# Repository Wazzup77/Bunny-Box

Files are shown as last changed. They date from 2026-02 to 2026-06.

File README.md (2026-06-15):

<p align="center">
  A bunny in the style of the Qidi Box
  <h1 align="center">Bunny Box</h1>
</p>

<p align="center">
Qidi Box open source makeover using Happy Hare
</p>

Bunny Box is the Qidi Box mod that allows you to ditch Qidi's closed-source, proprietary firmware and use [Happy Hare](https://github.com/moggieuk/Happy-Hare/) to control your Box. With added support for Qidi-specific qirks such as the extruder hall sensor and above-extruder cutter placement, this allows Qidi Box use with Freedi and Kalico as well as using non-Qidi multimaterial units with Qidi printers. Strong defaults are provided, but the beauty of Happy Hare is that almost anything can be tweaked!

## FEATURES

 * Open source alternative to Qidi's Box control
    * No more .so files (you can update Python again)
    * Full control over Qidi Box configuration
    * Make the Qidi Box work on older Qidi and non-Qidi printers

 * Fully featured Happy Hare
    * Tip forming - save filament by reducing waste
    * the entire loading process can be tinkered with - increase loading speeds, change toolchange sequences, etc.
    * Spoolman support for better filament management
    * configurable LED effects depending on print / filament state

 **NOT SUPPORTED:**
 * RFID tags - maybe in the future, but honestly who cares?

## DEVELOPMENT STATUS

 * [**Qidi Happy Hare fork**](https://github.com/Wazzup77/Happy-Hare) - works, but not yet pulled into mainline. The `bunnybox` branch is used as the installation source. Q2 and Max4 users can install mainline Happy Hare.
 * [**Plus4**](Plus4) - works, tested on Qidi's 1.7.3, FreeDi (so stock Klipper) and Kalico (with minor issues still to be resolved).
 * [**Q2**](Q2) - testing in progress!
 * [**Max4**](Max4) - **HACKERS WANTED** - The Max4 firmware stack is materially more complex than Plus4/Q2 - it's split into multiple smaller .cfg files and has additional closed-source modules. Brave volunteers that own the Max4 are encouraged to reach out and help figure it out!

 Should be compatible with Beacon/Cartographer mods.

## ISSUES / TODO
* Printer screen is broken on stock Qidi firmware while in print - probably won't be fixed
* Qidi Studio sync is not working
* Power-loss recovery is disabled. Qidi's PLR depends on closed-source code (binary `.so` on Plus4, shell scripts on Q2) and cannot restore MMU tool/gate state. The stock `DETECT_INTERRUPTION` popup ("Resume last print?") would auto-cancel on timeout and, even if accepted, would resume with the wrong filament. Our `bunnybox_macros.cfg` overrides `DETECT_INTERRUPTION` to silently clear the flag so the popup never appears.

If you run into issues please report them in the issue tracker here. We are also on Qidi's Discord server [in a dedicated thread](https://discord.com/channels/1184400034641477722/1443579858679500822) if you want to chat.

## HAPPY HARE FORK

We are for now relying on a fork of Happy Hare until our new features are pulled to mainline. This is necessary for handling of the hall effect sensor in the extruder of Qidi printers and Qidi's weird cutter configuration. 

[Happy Hare Qidi Fork](https://github.com/Wazzup77/Happy-Hare/).

## HARDWARE REFERENCE

* [Qidi Box Pinout](qidi_box_pinout.md)
* [Qidi Box DFU Flashing Guide](dfu_flash.md)

## ADDITIONAL HELP

Refer to the [Happy Hare documentation](https://github.com/moggieuk/Happy-Hare/wiki).

## Frequenty Asked Questions

<details>
<summary> Do I need to flash the Qidi Box firmware? </summary>

No! Qidi Box already runs Klipper (Qidi's fork). Since the Box is a slave to the host (printer), flashing is not needed regardless of if you are connecting to a Qidi printer, a Qidi printer flashed with FreeDi or Kalico, or a non-Qidi printer. Nonetheless, you can flash it - the instructions are [here](dfu_flash.md).

</details>

<details>
<summary> How do I go back to the stock firmware?  </summary>

Re-run the installer script for your printer ([Plus4](Plus4/install-bb-p4.sh), [Q2](Q2/install-bb-q2.sh), [Max4](Max4/install-bb-max4.sh)). If it detects an existing bunnybox install it will offer **2) Revert to stock**, which restores `printer.cfg` and the stock macro file from the oldest `backup_hh_*` directory and clears `mmu__revision`. The current bunnybox state is preserved in a new `backup_revert_<timestamp>/` so the revert itself can be undone.

To script the revert (no menu prompt), pass `--revert` to the installer — see the "Reverting to stock" section in each printer's README ([Plus4](Plus4/README.md#reverting-to-stock), [Q2](Q2/README.md#reverting-to-stock), [Max4](Max4/README.md#reverting-to-stock)).

If no `backup_hh_*` directory exists (e.g. the install was done manually), restore your own backups of `printer.cfg` and `gcode_macro.cfg` (or `klipper-macros-qd/` on Max4), delete the `mmu/` folder and `bunnybox_macros.cfg` from your config directory, remove the `mmu__revision` line from `saved_variables.cfg`, and restart Klipper.

</details>

<details>
<summary> How do I update without losing my tuning and calibration? </summary>

Just re-run the installer for your printer. When it detects an existing install and you choose **1) Reinstall / update**, your config is no longer overwritten wholesale. The update is split between two installers that own different parts of the config:

**Happy Hare's own installer** handles everything it manages: the MMU *logic* files (`mmu_cut_tip.cfg`, `mmu_sequence.cfg`, `mmu_software.cfg`, …, which it installs as symlinks into `~/Happy-Hare`), and your *parameters* (`mmu_parameters.cfg`, `mmu_macro_vars.cfg`, addon configs), whose values it carries forward as it upgrades them. **Your calibration (`mmu/mmu_vars.cfg`) is left untouched.** This is why the bundled copies of those files in this repo can look "behind" — they're only reference snapshots; the live versions come from the Happy Hare fork at install time.

**Bunny Box's smart merge** handles only the files Happy Hare leaves frozen and that Bunny Box truly owns: `mmu_hardware.cfg` (Qidi pins), `mmu.cfg`, the addon `*_hw.cfg` hardware files, and the top-level `bunnybox_macros.cfg`. For these it does a **3-way merge** against a snapshot of what it last installed (`printer_data/config/.bunnybox_base`, recorded by a `.bunnybox_manifest`):

* Files you never edited but that changed upstream are **updated to the new defaults** automatically.
* Files you edited but that didn't change upstream are **left exactly as you have them**.
* Files where your edits *and* the new defaults overlap are **merged**; if they collide on the same lines the installer **asks you per file** whether to keep yours, take the new version, or write a `*.bbmerge` copy with conflict markers to resolve by hand.

When run from a git clone it also prints a short **changelog** of the config commits between your installed version and the latest. A full backup is still saved to `backup_hh_<timestamp>/` every time, so any update is reversible.

> Note: the Bunny Box smart merge now ships on all three installers (**Plus4**, **Q2** and **Max4**). Plus4 installs Happy Hare from the [`bunnybox` fork](https://github.com/Wazzup77/Happy-Hare); Q2 and Max4 install mainline Happy Hare. In all cases Happy Hare's installer owns the logic/parameter upgrade and Bunny Box's smart merge owns the hardware/macro layer.

</details>

<details>
<summary> Can you add support for my printer? </summary>

I only have a Plus4 and so can't really make other printers work. There are people with the Q2 who are using Bunny Box though, so that will likely come soon. For the Max4, I don't have one, so that will only come if someone else makes it. As for older ones/non-Qidi printers, you're on your own - I don't have one and think it's unlikely anyone will make one for you.

</details>

<details>
<summary> I'm a bit of a noob, can you help me? </summary>

Unfortunately I probably won't be able to help you much - I'm pretty busy and issues with Happy Hare are very difficult to diagnose without having phyiscal access to the machine and full knowledge of its configuration. If you decide to use this, be aware that you are expected to read [Happy Hare documentation](https://github.com/moggieuk/Happy-Hare/wiki) and understand what you are doing.

</details>

<details>
<summary> I changed the speeds in mmu_parameters.cfg, why are loads weird now? </summary>

Qidi's encoder is not that great unfortunately. It's measurement will vary widely depending on speed. At the same time you cannot really adjust its sensitivity parameter, since it is used for clog detetion during print (when the filament is moving slowly). In effect, you should calibrate the lengts of tubes after changing speeds (using the encoder calibration routire in HH). 

</details>

<details>
<summary> My filament is grinding in the gears </summary>

Repeated load/unload cycles without any significant extrusion will cause the filament to grind in the gears. This is normal.

</details>

<details>
<summary> I'm getting false-positive runouts on filament changes! </summary>

You probably forgot to remove the runout from your [hall_filament_width_sensor] section in printer.cfg! Comment out the runout gcode and the pause on runout parameter, or remove the entire section.

</details>

<details>
<summary> I think my config is awesome, can I share it here? </summary>
Yes! Please create a PR. If you are able to make a distint configuration (e.g. for a different printer or compatible with stock Qidi gcode) please make a new folder for it and add a README describing the configuration and installation. Small configuration tweaks can be made to the base configs, but should be well described and justified.

</details>

<details>
<summary> I love this mod! Happy Hare is great! How can I make it even better!? </summary>
Fit a [proportional filament sensor (PFS)](addons/PFS) in place of the stock filament tangle sensor — it gives Happy Hare analog sync-feedback for tighter gear/extruder syncing and smarter clog/tangle detection. See [addons/PFS](addons/PFS/README.md) for the build, wiring and calibration guide.

</details>

## CONTRIBUTING

PRs are welcome! Just make sure to describe what system you're working with (Qidi Klipper, Klipper or Kalico) and what other mods you have.
We prefer strong defaults that should work with everyone here, even if they are not optimal. Go slower or more wasteful by default, let willing users tune it to their demands.

## SUPPORT THE PROJECT

[Support Happy Hare instead!](https://www.paypal.me/moggieuk)

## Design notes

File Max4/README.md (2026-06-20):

> [!CAUTION]
> **Max4 support is experimental — hackers wanted, do not install on a working printer.** The Max4 firmware stack is materially more complex than Plus4 or Q2 and the HH integration is only partially mapped out. If something fails, you are expected to diagnose and fix it.
>
> **What's different about the Max4:**
> - It adds a second closed-source state machine, `multi_color_controller.so`, on top of the `box_extras` / `box_autofeed` / `box_stepper` / `box_rfid` stack shared with Plus4/Q2. `multi_color_controller` implements both local orchestration and a USB-JSON protocol to the second-gen box.
> - The macro layer is built on [Justin Schuh's klipper-macros](https://github.com/jschuh/klipper-macros) (packaged as `klipper-macros-qd`) with a phased `PRINT_START` (`_PRINT_START_PHASE_INIT` → `_PRINT_START_BOX_PREPAR` → `_PRINT_START_PHASE_PREHEAT` → `_PRINT_START_PHASE_PROBING` → `_PRINT_START_PHASE_EXTRUDER`) rather than the single flat `gcode_macro.cfg` pattern of Plus4/Q2. Lowercase section names (`[gcode_macro pause]`, `[gcode_macro clear_pause]`) are used. This is more complex to modify and will require live testing which I cannot do (I do not own a Max4).
> - Closed-source dependencies extend beyond the box: `probe_air`, `multi_color_controller`, `d_bus_service_manager`, `ai_func_manager`, `print_stats_manager`, `smart_output_pin`, `cl_interface`, `closed_loop`. This should be avoidable, since Happy Hare allows us to remove Qidi box-related configs and thus prevent the .so files from loading. However, for the Max4, the .so files extend further beyond the Plus4/Q2 scope, so hidden dependancies may emerge.

# INSTALLATION

> [!IMPORTANT]
> **Unload all filament from the box before you start.** Once Happy Hare is installed you cannot load or unload filament until [calibration](#-calibration--required-before-first-use) is done, and gear calibration has to be performed with the filament cut flush at the gate — not fully loaded. Unload every gate now, while the stock Qidi firmware is still in control.

## AUTO INSTALLATION

The easiest way to install Happy Hare on your Qidi Max4 is to use the provided automated script. 

1. **Connect to your printer** via SSH.
2. **Download and run the script**:
   ```bash
   wget -qO - https://raw.githubusercontent.com/Wazzup77/Bunny-Box/refs/heads/main/Max4/install-bb-max4.sh | bash
   ```
   
The script will backup your configurations, download the necessary files, prompt you for your serial ID, and automatically install Happy Hare.
Don't forget to update the machine gcodes in the slicer to use the ones provided in the [slicer_machine_gcodes.md](./config_hh-standalone/slicer_machine_gcodes.md).

> [!CAUTION]
> **The installer does NOT calibrate your MMU.** After installation you MUST calibrate before your first print — see [CALIBRATION — REQUIRED BEFORE FIRST USE](#-calibration--required-before-first-use) at the bottom of this guide. This is the most commonly missed step.

## REVERTING TO STOCK

The installer script doubles as the uninstaller. Re-run it on a printer where bunnybox / Happy Hare is already installed and it will offer a revert option:

```bash
wget -qO - https://raw.githubusercontent.com/Wazzup77/Bunny-Box/refs/heads/main/Max4/install-bb-max4.sh | bash
```

When the menu appears, choose **2) Revert to stock**. The script will:
- restore `printer.cfg` and the `klipper-macros-qd/` directory from the oldest `backup_hh_*` directory (your pre-install snapshot),
- move the current `bunnybox_macros.cfg` and `mmu/` folder into a new `backup_revert_<timestamp>/` so the revert itself can be undone,
- clear `mmu__revision` from `saved_variables.cfg`, and
- restart Klipper and Moonraker with `sudo systemctl restart klipper` or a power cycle.

### Non-interactive revert (for scripts)

If you want to call the revert from another script, pass `--revert` to skip the menu entirely:

```bash
# Standalone (one-liner)
wget -qO - https://raw.githubusercontent.com/Wazzup77/Bunny-Box/refs/heads/main/Max4/install-bb-max4.sh | bash -s -- --revert

# Or from a cloned repo
./install-bb-max4.sh --revert
```

Use `--help` to see all flags. The revert leaves the cloned `~/Happy-Hare/` repo and the custom `aht10.py` module on disk; they are harmless once `printer.cfg` no longer references them.

## MANUAL INSTALLATION

### STEP 1: HAPPY HARE INSTALLATION
<details>
<summary> HAPPY HARE INSTALL </summary>

1. Select your config variant. At present, you can select from:

- [`config_hh-standalone`](./config_hh-standalone/README.md) - Happy Hare focused config, taking advantage of its features for a more Happy-Hare experience

2. Copy the configs (`mmu` folder and `bunnybox_macros.cfg`) from the selected variant to your printer's config folder.

3. Add your printer's serial address to `mmu/base/mmu.cfg`. To do this, connect to your printer via SSH and run:

```bash
ls /dev/serial/by-id/*
```

This will give you a list of USB devices. It should say something like:

```bash
/dev/serial/by-id/usb-Klipper_QIDI_BOX_xxxxxxxxxxxxxxxxxxxxxxxxxx
```

Copy that into your mmu.cfg in the `serial:` parameter, replacing the old value.

4. Install Happy Hare from the [Qidi Box fork](https://github.com/Wazzup77/Happy-Hare). To do this, connect to your printer via SSH and run:

```bash
cd ~
git clone -b bunnybox https://github.com/Wazzup77/Happy-Hare.git
```

5. Run the install script `Happy-Hare/install.sh` and pray that it does not break stuff.

```bash
./Happy-Hare/install.sh
```

6. Add `mmu__revision = 0` to `saved_variables.cfg'

```bash
echo "mmu__revision = 0" >> printer_data/config/saved_variables.cfg
```

7. Restart Klipper

```bash
sudo service klipper restart
```
</details>

### STEP 2: printer.cfg CHANGES

<details>
<summary> `[printer.cfg]` CHANGES </summary>

0. Backup your printer.cfg file! Just in case you want to return to the stock config.

1. Remove Qidi's stock box config `[include box.cfg]` and `[multi_color_controller]`.

2. Modify the `[filament_switch_sensor filament_switch_sensor]` section (HH takes care of runout). **Important:** Set `pause_on_runout` to `False` — do not comment it out, as Klipper defaults to `True`:
```diff
+[duplicate_pin_override]
+pins: THR:PA0
+
[filament_switch_sensor filament_switch_sensor]
-pause_on_runout: True
+pause_on_runout: False
-runout_gcode:
-            M118 Filament run out
-            {% set can_auto_reload = printer.save_variables.variables.auto_reload_detect|default(0) %}
-            {% if can_auto_reload == 1 %}
-              AUTO_RELOAD_FILAMENT
-            {% endif %}
-insert_gcode:             # Code executed when inserting consumables
event_delay: 3.0          # event delay time
pause_delay: 0.5          # pause delay time
switch_pin:!THR:PA0       # Detect switch pin
```

> **The installer does the `[duplicate_pin_override]` + pin sync for you** — it reads the stock sensor's `switch_pin` and writes it into both the override and `mmu_hardware.cfg`'s `extruder_switch_pin`. You only need this step if installing by hand.
>
> **FreeDi / Kalico users:** those firmwares may name the toolhead MCU something other than `THR` (e.g. `Toolhead`). If so, the stock `switch_pin` will read `Toolhead:PA0` (not `THR:PA0`), and `extruder_switch_pin` in `mmu_hardware.cfg` plus the `[duplicate_pin_override]` pin must use that **same** name. Copy it from your own printer.cfg — a hardcoded `THR` that doesn't exist fails to load with `MCU 'THR' not found`.

3. Add `[include bunnybox_macros.cfg]` at the top.

4. Make sure Happy Hare files were included during install in printer.cfg: 
```
[include mmu/base/*.cfg]
[include mmu/optional/client_macros.cfg]
```
Other mmu directories should not be included!

5. **Recommended:** Wrap the `[idle_timeout]` gcode so it does not kill the box heaters during a Happy Hare drying cycle (`MMU_HEATER DRY=1`). Without this, an `idle_timeout` shorter than your drying cycle will turn off the heaters mid-dry. Stock Qidi ships with `timeout: 43200` (12 hours), so this only matters if you've shortened the timeout or want to dry for longer than 12 hours.

```diff
[idle_timeout]
timeout: 43200
gcode:
-    PRINT_END
+    {% if printer.mmu is defined and printer.mmu.drying_state[0] == 'active' %}
+      SET_HEATER_TEMPERATURE HEATER=extruder TARGET=0
+      SET_HEATER_TEMPERATURE HEATER=heater_bed TARGET=0
+      SET_HEATER_TEMPERATURE HEATER=chamber TARGET=0
+    {% else %}
+      PRINT_END
+    {% endif %}
```

   If your `[idle_timeout]` section only has `timeout:` and no `gcode:` block, you are relying on Klipper's implicit default of `TURN_OFF_HEATERS` + `M84`. Add the wrapped block to the section, with `TURN_OFF_HEATERS` and `M84` as the `{% else %}` branch.

</details>

### STEP 3: klipper-macros-qd CHANGES

<details>
<summary> `klipper-macros-qd` CHANGES </summary>

0. Backup your `klipper-macros-qd` folder! Just in case you want to return to the stock config.

1. In `start_end.cfg`:
```diff
[gcode_macro print_start]
description: Usage: PRINT_START BED=<temp> HOTEND=<temp> [CHAMBER=<temp>] EXTRUDER = <num>
                     [MESH_MIN=<x,y>] [MESH_MAX=<x,y>] [LAYERS=<num>]
                     [NOZZLE_SIZE=<mm>]
gcode:
  # Set the printing master status to the starting stage
  SET_PRINT_MAIN_STATUS MAIN_STATUS=print_start
  # ===Print the four core stages of startup ===
  _PRINT_START_PHASE_INIT {rawparams}   # Phase 1: Initialize setup and start bed/chamber preheating
-  _PRINT_START_BOX_PREPAR               # Stage 2: Multi-color consumable preparation and switching

  _PRINT_START_PHASE_PREHEAT            # Phase 3: Temperature stabilization and shaft return
  _PRINT_START_PHASE_PROBING            # Stage 4: Detection calibration (bed net/gantry leveling)
  _PRINT_START_PHASE_EXTRUDER           # Stage 5: Final warm-up of the extruder
  # Switch to official printing status
  SET_PRINT_MAIN_STATUS MAIN_STATUS=printing
```
2. In `pause_resume_cancel.cfg`:
    - Remove `pause` / `PAUSE` (or comment it out — note Max4 stock uses lowercase).
    - Remove `RESUME_PRINT` (or comment it out).
    - Remove `RESUME` (or comment it out).
    - Remove `CANCEL_PRINT` (or comment it out).
    - Remove `clear_pause` (or comment it out — references variables on `RESUME_PRINT` so it would throw after step 2 above).

3. If any config file in your install defines `[gcode_macro DETECT_INTERRUPTION]`, comment it out. `bunnybox_macros.cfg` provides a no-op replacement; commenting rather than using `rename_existing:` keeps the install working on mainline Klipper / FreeDi where the stock macro may already be absent. (Stock Max4 does not define this macro in any visible config — this step is a no-op for stock Max4 installs.)

4. In `start_end.cfg`, comment out any `save_last_file` call inside `PRINT_START`. This is Qidi's power-loss recovery hook and sets `was_interrupted=True` in `saved_variables.cfg` on every print start; PLR is disabled under Happy Hare (see [DETECT_INTERRUPTION override](./config_hh-standalone/bunnybox_macros.cfg)) so the call is wasteful.

</details>

### STEP 4: USER INTERFACE

<details>
<summary> USER INTERFACE </summary>

If you want to have a section in your printer web interface, install baseline fluidd or mainsail, which both have HH implemented. You can do that via kiauh, which comes preinstalled on Qidi printers.

1. Update kiauh

```bash
    cd kiauh
    git pull
```

2. Run kiauh to reinstall fluidd or mainsail

```bash
    ./kiauh.sh
```

You want to REMOVE the existing Fluidd installation and install it again - this will move you from the Qidi version to mainline, which supports Happy Hare.
Alternatively you can also install Mainsail instead of Fluidd.

</details>

### STEP 5: SLICER SETTINGS

<details>
<summary> SLICER SETTINGS </summary>

Use the [following machine g-codes](./config_hh-standalone/slicer_machine_gcodes_hh.md) with your slicer.

</details>

### (optional) STEP 6: ENVIRONMENT SENSOR

<details>
<summary> ENVIRONMENT SENSOR </summary>

> If you are on mainline Klipper, Freedi or Kalico, you can skip this step altogether, though it won't hurt anything if you do it. I recommend doing this step for stability, but you can skip it by changing the `[temperature_sensor box1_env]` `sensor_type` to `AHT10` in the `mmu_hardware.cfg`. 

To be able to view temperature and humidity in the printer web interface reliably, you need to install a aht10.py module from modern Klipper. 

1. Go to the Klipper directory and clone the module

```bash
    cd klipper/klippy/extras

    sudo mv aht10.py aht10.py.bak

    wget https://raw.githubusercontent.com/Wazzup77/Bunny-Box/refs/heads/main/aht10.py
```

</details>

# ⚠️ CALIBRATION — REQUIRED BEFORE FIRST USE

> [!CAUTION]
> **Happy Hare will NOT load filament or print reliably until it is calibrated.** Whether you used the auto installer or installed manually, calibration is a separate, mandatory step done once after installation, before your first print. It is the single most commonly missed step.

On the Max4 (no encoder):

- **Gear calibration** (`MMU_CALIBRATE_GEAR`) — ✅ **REQUIRED**
- Bowden length (`MMU_CALIBRATE_BOWDEN`) — *optional*

Follow the official [Happy Hare — Type B Calibration wiki](https://github.com/moggieuk/Happy-Hare/wiki/MMU-Calibration-TypeB) for the exact procedure and commands.

# ADDITIONAL TUNING

1. Speed! The default Qidi profile is very slow. You can speed it up by increasing the values in the SPEEDS section in mmu_parameters.cfg. Keep in mind that these settings will vary between different Qidi Boxes. Generally loading speeds can be increased by 20-30% without issues, but keep in mind that going fast may cause filament swaps to fail. Going too fast may also cause the filament to be ground up by the gears. Remember to recalibrate the encoder after changing speeds (its measurement will vary widely depending on speed).
2. Tip forming. The base configuration uses the cutter. Tip forming allows you to reduce filament waste by removing the whole filament piece from the hotend. The disadvantage is that good tuning is needed to avoid clogs. Although the profile in these configs has been tested on multiple filaments across multiple Plus4 printers, it may require tuning on your specific printer/filament. If you have a custom hotend, you need to update the configration too. Activate it by changing: 
`form_tip_macro: _MMU_CUT_TIP` to `form_tip_macro: _MMU_FORM_TIP`
To additionally improve the movement logic on tip forming (by moving to the purge chute first) add `toolchange` to the list of paramters at `variable_enable_park_printing` as such:
`variable_enable_park_printing   : 'toolchange,runout,load,complete,pause,cancel'	; Empty '' to disable parking`
If you ever want to switch back to cutting, remove the `toolchange` and revert to `form_tip_macro: _MMU_CUT_TIP`.

# ADDITIONAL HELP

Refer to the [Happy Hare documentation](https://github.com/moggieuk/Happy-Hare/wiki).

# ADVANCED USERS ONLY

Happy Hare allows for a lot of configuration - we will place interesting options and more install steps here.

- [Happy Hare Standalone](hh-standalone) - focused on using Happy Hare to the best of its ability - at the cost of being incompatible with stock Qidi gcode.
-

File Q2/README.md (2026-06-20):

# INSTALLATION

> [!IMPORTANT]
> **Unload all filament from the box before you start.** Once Happy Hare is installed you cannot load or unload filament until [calibration](#-calibration--required-before-first-use) is done, and gear calibration has to be performed with the filament cut flush at the gate — not fully loaded. Unload every gate now, while the stock Qidi firmware is still in control.

## AUTO INSTALLATION

The easiest way to install Happy Hare on your Qidi Q2 is to use the provided automated script. 

1. **Connect to your printer** via SSH.
2. **Download and run the script**:
   ```bash
   wget -qO - https://raw.githubusercontent.com/Wazzup77/Bunny-Box/refs/heads/main/Q2/install-bb-q2.sh | bash
   ```
   
The script will backup your configurations, download the necessary files, prompt you for your serial ID, and automatically install Happy Hare.

Don't forget to update the machine gcodes in the slicer to use the ones provided in the [slicer_machine_gcodes.md](./config_hh-standalone/slicer_machine_gcodes.md).

> [!CAUTION]
> **The installer does NOT calibrate your MMU.** After installation you MUST calibrate before your first print — see [CALIBRATION — REQUIRED BEFORE FIRST USE](#-calibration--required-before-first-use) at the bottom of this guide. This is the most commonly missed step.

## REVERTING TO STOCK

The installer script doubles as the uninstaller. Re-run it on a printer where bunnybox / Happy Hare is already installed and it will offer a revert option:

```bash
wget -qO - https://raw.githubusercontent.com/Wazzup77/Bunny-Box/refs/heads/main/Q2/install-bb-q2.sh | bash
```

When the menu appears, choose **2) Revert to stock**. The script will:
- restore `printer.cfg` and `gcode_macro.cfg` from the oldest `backup_hh_*` directory (your pre-install snapshot),
- move the current `bunnybox_macros.cfg` and `mmu/` folder into a new `backup_revert_<timestamp>/` so the revert itself can be undone,
- clear `mmu__revision` from `saved_variables.cfg`, and
- restart Klipper and Moonraker with `sudo systemctl restart klipper` or a power cycle.

### Non-interactive revert (for scripts)

If you want to call the revert from another script, pass `--revert` to skip the menu entirely:

```bash
# Standalone (one-liner)
wget -qO - https://raw.githubusercontent.com/Wazzup77/Bunny-Box/refs/heads/main/Q2/install-bb-q2.sh | bash -s -- --revert

# Or from a cloned repo
./install-bb-q2.sh --revert
```

Use `--help` to see all flags. The revert leaves the cloned `~/Happy-Hare/` repo and the custom `aht10.py` module on disk; they are harmless once `printer.cfg` no longer references them.

## MANUAL INSTALLATION

### HAPPY HARE INSTALLATION
<details>
<summary> STEP 1: HAPPY HARE INSTALL </summary>

1. Select your config variant. At present, you can select from:

- [`config_hh-standalone`](./config_hh-standalone/README.md) - Happy Hare focused config, taking advantage of its features for a more Happy-Hare experience

2. Copy the configs (`mmu` folder and `bunnybox_macros.cfg`) from the selected variant to your printer's config folder.

3. Add your printer's serial address to `mmu/base/mmu.cfg`. To do this, connect to your printer via SSH and run:

```bash
ls /dev/serial/by-id/*
```

This will give you a list of USB devices. It should say something like:

```bash
/dev/serial/by-id/usb-Klipper_QIDI_BOX_V1_1.1.1_xxxxxxxxxxxxxxxxxxxxxxxxxx
```

Copy that into your mmu.cfg in the `serial:` parameter, replacing the old value.

4. Install Happy Hare from the [Qidi Box fork](https://github.com/Wazzup77/Happy-Hare). To do this, connect to your printer via SSH and run:

```bash
cd ~
git clone -b bunnybox https://github.com/Wazzup77/Happy-Hare.git
```

5. Run the install script `Happy-Hare/install.sh` and pray that it does not break stuff.

```bash
./Happy-Hare/install.sh
```

6. Add `mmu__revision = 0` to `saved_variables.cfg'

```bash
echo "mmu__revision = 0" >> printer_data/config/saved_variables.cfg
```

7. Restart Klipper

```bash
sudo service klipper restart
```
</details>

### STEP 2:printer.cfg CHANGES

<details>
<summary> `[printer.cfg]` CHANGES </summary>

0. Backup your printer.cfg file! Just in case you want to return to the stock config.

1. Remove Qidi's stock box config `[include box.cfg]`.

2. Add `[include bunnybox_macros.cfg]` at the top.

3. Make sure Happy Hare files were included during install in printer.cfg: 
```
[include mmu/base/*.cfg]
[include mmu/optional/client_macros.cfg]
```
Other mmu directories should not be included!

4. Modify the `[filament_switch_sensor filament_switch_sensor]` section (HH takes care of runout). **Important:** Set `pause_on_runout` to `False` — do not comment it out, as Klipper defaults to `True`:
```diff
+[duplicate_pin_override]
+pins: THR:PA1
+
[filament_switch_sensor filament_switch_sensor]
-pause_on_runout: True
+pause_on_runout: False
-runout_gcode:
-            M118 Filament run out
-            {% set can_auto_reload = printer.save_variables.variables.auto_reload_detect|default(0) %}
-            {% if can_auto_reload == 1 %}
-              AUTO_RELOAD_FILAMENT
-            {% endif %}
-insert_gcode:             # Code executed when inserting consumables
event_delay: 3.0          # event delay time
pause_delay: 0.5          # pause delay time
switch_pin:!THR:PA1       # Detect switch pin
```

> **The installer does the `[duplicate_pin_override]` + pin sync for you** — it reads the stock sensor's `switch_pin` and writes it into both the override and `mmu_hardware.cfg`'s `extruder_switch_pin`. You only need this step if installing by hand.
>
> **FreeDi / Kalico users:** those firmwares may name the toolhead MCU something other than `THR` (e.g. `Toolhead`). If so, the stock `switch_pin` will read `Toolhead:PA1` (not `THR:PA1`), and `extruder_switch_pin` in `mmu_hardware.cfg` plus the `[duplicate_pin_override]` pin must use that **same** name. Copy it from your own printer.cfg — a hardcoded `THR` that doesn't exist fails to load with `MCU 'THR' not found`.

5. **Recommended:** Wrap the `[idle_timeout]` gcode so it does not kill the box heaters during a Happy Hare drying cycle (`MMU_HEATER DRY=1`). Without this, an `idle_timeout` shorter than your drying cycle will turn off the heaters mid-dry. Stock Qidi ships with `timeout: 43200` (12 hours), so this only matters if you've shortened the timeout or want to dry for longer than 12 hours.

```diff
[idle_timeout]
timeout: 43200
gcode:
-    PRINT_END
+    {% if printer.mmu is defined and printer.mmu.drying_state[0] == 'active' %}
+      SET_HEATER_TEMPERATURE HEATER=extruder TARGET=0
+      SET_HEATER_TEMPERATURE HEATER=heater_bed TARGET=0
+      SET_HEATER_TEMPERATURE HEATER=chamber TARGET=0
+    {% else %}
+      PRINT_END
+    {% endif %}
```

   If your `[idle_timeout]` section only has `timeout:` and no `gcode:` block, you are relying on Klipper's implicit default of `TURN_OFF_HEATERS` + `M84`. Add the wrapped block to the section, with `TURN_OFF_HEATERS` and `M84` as the `{% else %}` branch.

</details>

### STEP 3: gcode_macro.cfg CHANGES

<details>
<summary> `[gcode_macro.cfg]` CHANGES </summary>

0. Backup your gcode_macro.cfg file! Just in case you want to return to the stock config.

1. In `PRINT_START` we need to change Box detection logic:
```diff
[gcode_macro PRINT_START]
gcode:
[...]
-    {% if printer.save_variables.variables.box_count >= 1 %} 
+    {% if printer.mmu.num_gates >= 4 %} 
        SAVE_VARIABLE VARIABLE=load_retry_num VALUE=0
        SAVE_VARIABLE VARIABLE=retry_step VALUE=None
        CLEAR_TOOLCHANGE_STATE
        {% for i in range(16) %}
            SAVE_VARIABLE VARIABLE=runout_{i} VALUE=0
            G4 P100
        {% endfor %}
-        {% if printer.save_variables.variables.enable_box == 1 %}
+        {% if printer.mmu.enabled %}
            BOX_PRINT_START EXTRUDER={extruder} HOTENDTEMP={hotendtemp}
            M400
            EXTRUSION_AND_FLUSH HOTEND={hotendtemp}
        {% endif %}
[...]
```

2. Remove `PAUSE` (or comment it out).

3. Remove `RESUME_PRINT` (or comment it out).

4. Remove `RESUME` (or comment it out).

5. Remove `CANCEL_PRINT` (or comment it out).

6. Remove `DETECT_INTERRUPTION` (or comment it out). `bunnybox_macros.cfg` provides a no-op replacement; commenting the stock macro out (rather than relying on `rename_existing:`) keeps the install working on mainline Klipper / FreeDi where the stock macro may already be absent.

7. Comment out the `save_last_file` call at the end of `PRINT_START`. This is Qidi's power-loss recovery hook (defined in `plr.cfg`) and sets `was_interrupted=True` in `saved_variables.cfg` on every print start; PLR is disabled under Happy Hare (see [DETECT_INTERRUPTION override](./config_hh-standalone/bunnybox_macros.cfg)) so the call is wasteful.
```diff
     SET_PRINT_STATS_INFO CURRENT_LAYER=1
     ENABLE_ALL_SENSOR
-    save_last_file
+#    save_last_file
```

</details>

### STEP 4: USER INTERFACE

<details>
<summary> USER INTERFACE </summary>

If you want to have a section in your printer web interface, install baseline fluidd or mainsail, which both have HH implemented. You can do that via kiauh, which comes preinstalled on Qidi printers.

1. Update kiauh

```bash
    cd kiauh
    git pull
```

2. Run kiauh to reinstall fluidd or mainsail

```bash
    ./kiauh.sh
```

You want to REMOVE the existing Fluidd installation and install it again - this will move you from the Qidi version to mainline, which supports Happy Hare.
Alternatively you can also install Mainsail instead of Fluidd.

</details>

### STEP 5: SLICER SETTINGS

<details>
<summary> SLICER SETTINGS </summary>

Go into your pritner settings in the slicer and change them to use the [following machine g-codes](./config_hh-standalone/slicer_machine_gcodes_hh.md).

</details>

### (optional) STEP 6: ENVIRONMENT SENSOR

<details>
<summary> ENVIRONMENT SENSOR </summary>

> If you are on mainline Klipper, Freedi or Kalico, you can skip this step altogether, though it won't hurt anything if you do it. I recommend doing this step for stability, but you can skip it by changing the `[temperature_sensor box1_env]` `sensor_type` to `AHT10` in the `mmu_hardware.cfg`. 

To be able to view temperature and humidity in the printer web interface reliably, you need to install a aht10.py module from modern Klipper. 

1. Go to the Klipper directory and clone the module

```bash
    cd klipper/klippy/extras

    sudo mv aht10.py aht10.py.bak

    wget https://raw.githubusercontent.com/Wazzup77/Bunny-Box/refs/heads/main/aht10.py
```

</details>

# ⚠️ CALIBRATION — REQUIRED BEFORE FIRST USE

> [!CAUTION]
> **Happy Hare will NOT load filament or print reliably until it is calibrated.** Whether you used the auto installer or installed manually, calibration is a separate, mandatory step done once after installation, before your first print. It is the single most commonly missed step.

On the Q2:

- **Gear calibration** (`MMU_CALIBRATE_GEAR`) — ✅ **REQUIRED**
- Bowden length (`MMU_CALIBRATE_BOWDEN`) — *optional*

Follow the official [Happy Hare — Type B Calibration wiki](https://github.com/moggieuk/Happy-Hare/wiki/MMU-Calibration-TypeB) for the exact procedure and commands.

# ADDITIONAL TUNING

## Speed 

The default Qidi profile is very slow. You can speed it up by increasing the values in the SPEEDS section in mmu_parameters.cfg. Keep in mind that these settings will vary between different Qidi Boxes. Generally loading speeds can be increased by 20-30% without issues, but keep in mind that going fast may cause filament swaps to fail. Going too fast may also cause the filament to be ground up by the gears. Remember to recalibrate the encoder after changing speeds (its measurement will vary widely depending on speed).

## Tip forming

The base configuration uses the cutter. Tip forming allows you to reduce filament waste by removing the whole filament piece from the hotend. The disadvantage is that good tuning is needed to avoid clogs. Although the profile in these configs has been tested on multiple filaments across multiple Plus4 printers, it may require tuning on your specific printer/filament. If you have a custom hotend, you need to update the configration too. Activate it by changing: 

`form_tip_macro: _MMU_CUT_TIP` to `form_tip_macro: _MMU_FORM_TIP`

To additionally improve the movement logic on tip forming (by moving to the purge chute first) add `toolchange` to the list of paramters at `variable_enable_park_printing` as such:

`variable_enable_park_printing   : 'toolchange,runout,load,complete,pause,cancel'	; Empty '' to disable parking`

If you ever want to switch back to cutting, remove the `toolchange` and revert to `form_tip_macro: _MMU_CUT_TIP`.

# FAQ

1. Q: I'm getting `Move out of range` errors on filament change operations.

A: This is probably caused by skew correction. On the Q2 the cutter pin is very close to the lower movement limit on the X axis (X=-1). You can correct this by making small changes in `mmu_macro_vars.cfg`, either by:
* (recommended) disabling the skew correction for the unload operation
```
variable_user_pre_unload_extension    : 'SET_SKEW CLEAR=1'    ; Executed after default logic
variable_user_post_unload_extension   : 'SET_SKEW CLEAR=[your profile name]'    ; Executed after default logic
```
OR
* (easier, but kinda dirty) moving the `variable_pin_loc_xy` up by a bit on the X axis (e.g. to -0.9) 

# ADDITIONAL HELP

Refer to the [Happy Hare documentation](https://github.com/moggieuk/Happy-Hare/wiki).

# ADVANCED USERS ONLY

Happy Hare allows for a lot of configuration - we will place interesting options and more install steps here.

- [Happy Hare Standalone](hh-standalone) - focused on using Happy Hare to the best of its ability - at the cost of being incompatible with stock Qidi gcode.

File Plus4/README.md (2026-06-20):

# INSTALLATION

> [!IMPORTANT]
> **Unload all filament from the box before you start.** Once Happy Hare is installed you cannot load or unload filament until [calibration](#-calibration--required-before-first-use) is done, and gear calibration has to be performed with the filament cut flush at the gate — not fully loaded. Unload every gate now, while the stock Qidi firmware is still in control.

## AUTO INSTALLATION

The easiest way to install Happy Hare on your Qidi Plus4 is to use the provided automated script. 

1. **Connect to your printer** via SSH.
2. **Download and run the script**:
   ```bash
   wget -qO - https://raw.githubusercontent.com/Wazzup77/Bunny-Box/refs/heads/main/Plus4/install-bb-p4.sh | bash
   ```
   
The script will backup your configurations, download the necessary files, prompt you for your serial ID, and automatically install Happy Hare.
Don't forget to update the machine gcodes in the slicer to use the ones provided in the [slicer_machine_gcodes.md](./config_hh-standalone/slicer_machine_gcodes.md).

> [!CAUTION]
> **The installer does NOT calibrate your MMU.** After installation you MUST calibrate before your first print — see [CALIBRATION — REQUIRED BEFORE FIRST USE](#-calibration--required-before-first-use) at the bottom of this guide. This is the most commonly missed step.

## REVERTING TO STOCK

The installer script doubles as the uninstaller. Re-run it on a printer where bunnybox / Happy Hare is already installed and it will offer a revert option:

```bash
wget -qO - https://raw.githubusercontent.com/Wazzup77/Bunny-Box/refs/heads/main/Plus4/install-bb-p4.sh | bash
```

When the menu appears, choose **2) Revert to stock**. The script will:
- restore `printer.cfg` and `gcode_macro.cfg` from the oldest `backup_hh_*` directory (your pre-install snapshot),
- move the current `bunnybox_macros.cfg` and `mmu/` folder into a new `backup_revert_<timestamp>/` so the revert itself can be undone,
- clear `mmu__revision` from `saved_variables.cfg`, and
- restart Klipper and Moonraker with `sudo systemctl restart klipper` or a power cycle.

### Non-interactive revert (for scripts)

If you want to call the revert from another script, pass `--revert` to skip the menu entirely:

```bash
# Standalone (one-liner)
wget -qO - https://raw.githubusercontent.com/Wazzup77/Bunny-Box/refs/heads/main/Plus4/install-bb-p4.sh | bash -s -- --revert

# Or from a cloned repo
./install-bb-p4.sh --revert
```

Use `--help` to see all flags. The revert leaves the cloned `~/Happy-Hare/` repo and the custom `aht10.py` module on disk; they are harmless once `printer.cfg` no longer references them.

## MANUAL INSTALLATION

### HAPPY HARE INSTALLATION
<details>
<summary> STEP 1: HAPPY HARE INSTALL </summary>

1. Select your config variant. At present, you can select from:

- [`config_hh-standalone`](./config_hh-standalone/README.md) - Happy Hare focused config, taking advantage of its features for a more Happy-Hare experience

2. Copy the configs (`mmu` folder and `bunnybox_macros.cfg`) from the selected variant to your printer's config folder.

3. Add your printer's serial address to `mmu/base/mmu.cfg`. To do this, connect to your printer via SSH and run:

```bash
ls /dev/serial/by-id/*
```

This will give you a list of USB devices. It should say something like:

```bash
/dev/serial/by-id/usb-Klipper_QIDI_BOX_V1_1.1.1_xxxxxxxxxxxxxxxxxxxxxxxxxx
```

Copy that into your mmu.cfg in the `serial:` parameter, replacing the old value.

4. Install Happy Hare from the [Qidi Box fork](https://github.com/Wazzup77/Happy-Hare). To do this, connect to your printer via SSH and run:

```bash
cd ~
git clone -b bunnybox https://github.com/Wazzup77/Happy-Hare.git
```

5. Run the install script `Happy-Hare/install.sh` and pray that it does not break stuff.

```bash
./Happy-Hare/install.sh
```

6. Add `mmu__revision = 0` to `saved_variables.cfg'

```bash
echo "mmu__revision = 0" >> printer_data/config/saved_variables.cfg
```

7. Restart Klipper

```bash
sudo service klipper restart
```
</details>

### STEP 2:printer.cfg CHANGES

<details>
<summary> `[printer.cfg]` CHANGES </summary>

0. Backup your printer.cfg file! Just in case you want to return to the stock config.

1. Remove Qidi's stock box config `[include box.cfg]`.

2. Add `[include bunnybox_macros.cfg]` at the top.

3. **Recommended:** Comment out or delete the entire `[hall_filament_width_sensor]` section. It reads `adc1: PA2` and `adc2: PA3` — the same pins the MMU uses for `extruder_switch_pin`/`extruder_switch_pin2`. Two ADC readers on the same pins can cause `Timer too close` MCU crashes. The MMU already provides filament detection, so the stock hall sensor is redundant.

   > **The installer does this for you** (it comments the section out and copies `adc1`/`adc2` into `extruder_switch_pin`/`extruder_switch_pin2`), so you only need this step if installing by hand.
   >
   > **FreeDi / Kalico users, read this:** on those firmwares the toolhead is a *separate MCU*, so the stock sensor reads `Toolhead:PA2` / `Toolhead:PA3`, not a bare `PA2`/`PA3`. A bare pin name binds to the **main** MCU — an unconnected pin that floats and triggers a false "filament runout at extruder" the moment a print starts. Set `extruder_switch_pin`/`extruder_switch_pin2` in `mmu_hardware.cfg` to **exactly** whatever your stock `[hall_filament_width_sensor]`'s `adc1`/`adc2` were (e.g. `Toolhead:PA2` / `Toolhead:PA3`). Note the MCU is named differently per firmware — copy the name from your own printer.cfg.

   If you prefer to keep the section (not recommended), modify it as follows (removing or commenting out the red lines, and setting `pause_on_runout` to `False`):
```diff
[hall_filament_width_sensor]
adc1: PA2
adc2: PA3
cal_dia1: 1.50
cal_dia2: 2.0
raw_dia1: 14197
raw_dia2: 15058
default_nominal_filament_diameter: 1.75
max_difference: 0
measurement_delay: 50
enable: false
measurement_interval: 10
logging: False
-min_diameter: 0.3
-use_current_dia_while_delay: False
+pause_on_runout: False
-runout_gcode:
-            RESET_FILAMENT_WIDTH_SENSOR
-            M118 Filament run out
-            {% set can_auto_reload = printer.save_variables.variables.auto_reload_detect|default(0) %}
-            {% if can_auto_reload == 1 %}
-              AUTO_RELOAD_FILAMENT
-            {% endif %}
-event_delay: 3.0
-pause_delay: 0.5
```

3b. **Also disable the stock filament-tangle switch.** Separately from the hall sensor, the Plus4 has a `[filament_switch_sensor fila]` section (a microswitch on `switch_pin: U_1:PC3`). It ships with `pause_on_runout: True`, so it can pause the print on its own when it trips — independently of the MMU — and Happy Hare warns about it at every boot (`Warning: filament_switch_sensor 'fila' found in printer configuration...`). Happy Hare handles runout via its own sensors, so set `pause_on_runout` to `False` (do not just comment the line — Klipper defaults it back to `True`) and comment out the `runout_gcode`:
```diff
[filament_switch_sensor fila]
-pause_on_runout: True
+pause_on_runout: False
-runout_gcode:
-    M118 Filament tangle detected
-event_delay: 3.0
-pause_delay: 0.5
switch_pin: U_1:PC3
```
   The auto-installer now does this for you; this step is only needed for manual installs, or for existing installs set up before this was added.

4. Make sure Happy Hare files were included during install in printer.cfg: 
```
[include mmu/base/*.cfg]
[include mmu/optional/client_macros.cfg]
```
Other mmu directories should not be included!

5. **Recommended:** Wrap the `[idle_timeout]` gcode so it does not kill the box heaters during a Happy Hare drying cycle (`MMU_HEATER DRY=1`). Without this, an `idle_timeout` shorter than your drying cycle will turn off the heaters mid-dry. Stock Qidi ships with `timeout: 43200` (12 hours), so this only matters if you've shortened the timeout or want to dry for longer than 12 hours.

```diff
[idle_timeout]
timeout: 43200
gcode:
-    PRINT_END
+    {% if printer.mmu is defined and printer.mmu.drying_state[0] == 'active' %}
+      SET_HEATER_TEMPERATURE HEATER=extruder TARGET=0
+      SET_HEATER_TEMPERATURE HEATER=heater_bed TARGET=0
+      SET_HEATER_TEMPERATURE HEATER=chamber TARGET=0
+    {% else %}
+      PRINT_END
+    {% endif %}
```

   If your `[idle_timeout]` section only has `timeout:` and no `gcode:` block, you are relying on Klipper's implicit default of `TURN_OFF_HEATERS` + `M84`. Add the wrapped block to the section, with `TURN_OFF_HEATERS` and `M84` as the `{% else %}` branch.

</details>

### STEP 3: gcode_macro.cfg CHANGES

<details>
<summary> `[gcode_macro.cfg]` CHANGES </summary>

0. Backup your gcode_macro.cfg file! Just in case you want to return to the stock config.

1. In PRINT_START we need to change Box detection logic:
```diff
[gcode_macro PRINT_START]
gcode:
[...]
-    {% if printer.save_variables.variables.box_count >= 1 %} 
+    {% if printer.mmu.num_gates >= 4 %} 
        SAVE_VARIABLE VARIABLE=load_retry_num VALUE=0 # saved variables probably need a rework
        SAVE_VARIABLE VARIABLE=retry_step VALUE=None
        SAVE_VARIABLE VARIABLE=is_tool_change VALUE=0
        {% for i in range(16) %}
            SAVE_VARIABLE VARIABLE=runout_{i} VALUE=0
            G4 P100
        {% endfor %}
        SAVE_VARIABLE VARIABLE=extrude_state VALUE=-1
-        {% if printer.save_variables.variables.enable_box == 1 %}
+        {% if printer.mmu.enabled %}
            BOX_PRINT_START EXTRUDER={extruder} HOTENDTEMP={hotendtemp}
            M400
            EXTRUSION_AND_FLUSH HOTEND={hotendtemp}
        {% endif %}
[...]
```

2. Remove `PAUSE` (or comment it out).

3. Remove `RESUME_PRINT` (or comment it out).

4. Remove `RESUME` (or comment it out).

5. Remove `CANCEL_PRINT` (or comment it out).

6. Remove `DETECT_INTERRUPTION` (or comment it out). `bunnybox_macros.cfg` provides a no-op replacement; commenting the stock macro out (rather than relying on `rename_existing:`) keeps the install working on mainline Klipper / FreeDi where the stock macro may already be absent.

7. Comment out the `save_last_file` call at the end of `PRINT_START`. This is Qidi's power-loss recovery hook and sets `was_interrupted=True` in `saved_variables.cfg` on every print start; PLR is disabled under Happy Hare (see [DETECT_INTERRUPTION override](./config_hh-standalone/bunnybox_macros.cfg)) so the call is wasteful.
```diff
     SET_PRINT_STATS_INFO CURRENT_LAYER=1
     ENABLE_ALL_SENSOR
-    save_last_file
+#    save_last_file
```

</details>

### STEP 4: USER INTERFACE

<details>
<summary> USER INTERFACE </summary>

If you want to have a section in your printer web interface, install baseline fluidd or mainsail, which both have HH implemented. You can do that via kiauh, which comes preinstalled on Qidi printers.

1. Update kiauh

```bash
    cd kiauh
    git pull
```

2. Run kiauh to reinstall fluidd or mainsail

```bash
    ./kiauh.sh
```

You want to REMOVE the existing Fluidd installation and install it again - this will move you from the Qidi version to mainline, which supports Happy Hare.
Alternatively you can also install Mainsail instead of Fluidd.

</details>

### STEP 5: SLICER SETTINGS

<details>
<summary> SLICER SETTINGS </summary>

Go into your pritner settings in the slicer and change them to use the [following machine g-codes](./config_hh-standalone/slicer_machine_gcodes_hh.md).

</details>

### (optional) STEP 6: ENVIRONMENT SENSOR

<details>
<summary> ENVIRONMENT SENSOR </summary>

> If you are on mainline Klipper, Freedi or Kalico, you can skip this step altogether, though it won't hurt anything if you do it. I recommend doing this step for stability, but you can skip it by changing the `[temperature_sensor box1_env]` `sensor_type` to `AHT10` in the `mmu_hardware.cfg`. 

To be able to view temperature and humidity in the printer web interface reliably, you need to install a aht10.py module from modern Klipper. 

1. Go to the Klipper directory and clone the module

```bash
    cd klipper/klippy/extras

    sudo mv aht10.py aht10.py.bak

    wget https://raw.githubusercontent.com/Wazzup77/Bunny-Box/refs/heads/main/aht10.py
```

</details>

# ⚠️ CALIBRATION — REQUIRED BEFORE FIRST USE

> [!CAUTION]
> **Happy Hare will NOT load filament or print reliably until it is calibrated.** Whether you used the auto installer or installed manually, calibration is a separate, mandatory step done once after installation, before your first print. It is the single most commonly missed step.

On the Plus4:

- **Gear calibration** (`MMU_CALIBRATE_GEAR`) — ⚠️ **REQUIRED**
- **Encoder calibration** (`MMU_CALIBRATE_ENCODER`) — ⚠️ **REQUIRED**
- Bowden length (`MMU_CALIBRATE_BOWDEN`) and per-gate (`MMU_CALIBRATE_GATES`) — *optional*

Follow the official [Happy Hare — Type B Calibration wiki](https://github.com/moggieuk/Happy-Hare/wiki/MMU-Calibration-TypeB) for the exact procedure and commands.

# ADDITIONAL TUNING

1. Speed! The default Qidi profile is very slow. You can speed it up by increasing the values in the SPEEDS section in mmu_parameters.cfg. Keep in mind that these settings will vary between different Qidi Boxes. Generally loading speeds can be increased by 20-30% without issues, but keep in mind that going fast may cause filament swaps to fail. Going too fast may also cause the filament to be ground up by the gears. Remember to recalibrate the encoder after changing speeds (its measurement will vary widely depending on speed).
2. Tip forming. The base configuration uses the cutter. Tip forming allows you to reduce filament waste by removing the whole filament piece from the hotend. The disadvantage is that good tuning is needed to avoid clogs. Although the profile in these configs has been tested on multiple filaments across multiple Plus4 printers, it may require tuning on your specific printer/filament. If you have a custom hotend, you need to update the configration too. Activate it by changing:

`form_tip_macro: _MMU_CUT_TIP` to `form_tip_macro: _MMU_FORM_TIP`

To additionally improve the movement logic on tip forming (by moving to the purge chute first) add `toolchange` to the list of paramters at `variable_enable_park_printing` as such:

`variable_enable_park_printing   : 'toolchange,runout,load,complete,pause,cancel'	; Empty '' to disable parking`

If you ever want to switch back to cutting, remove the `toolchange` and revert to `form_tip_macro: _MMU_CUT_TIP`.

# ADDITIONAL HELP

Refer to the [Happy Hare documentation](https://github.com/moggieuk/Happy-Hare/wiki).

# ADVANCED USERS ONLY

Happy Hare allows for a lot of configuration - we will place interesting options and more install steps here.

- [Happy Hare Standalone](hh-standalone) - focused on using Happy Hare to the best of its ability - at the cost of being incompatible with stock Qidi gcode.
-

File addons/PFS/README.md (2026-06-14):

# Proportional Filament Sensor (PFS) — analog sync-feedback for Bunny Box

> [!NOTE]
> This has only been installed on a Qidi Plus4 so far, but nothing stops it being used on other printers — the Happy Hare config is generic, only the wiring and mounting are Plus4-specific. The mount is still a first pass (see [Mounting](#3-mounting--orientation)) and the spring is softer than the stock sensor, so expect some tuning. A better mount and reports from other printers are very welcome — open a PR or ping us on Discord.

A Proportional Filament Sensor (PFS) is a Hall-effect sync-feedback ("buffer") sensor for Happy Hare. Instead of a simple compression/tension switch it reports a continuous analog value of how compressed or tensioned the filament is between the MMU and the extruder. Happy Hare reads this on an ADC pin and uses it to keep the gear and extruder steppers in sync while printing (`sync_to_extruder`) and to drive FlowGuard clog/tangle detection. This is Happy Hare's analog / proportional (Type-P) feedback class — see the [Happy Hare sync-feedback docs](https://github.com/moggieuk/Happy-Hare/wiki/Synchronized-Gear-Extruder#---sync-feedback-sensor-options) for the theory.

Credit for the CAD files goes to [@fxwoody](https://www.youtube.com/@frankthebum)! ❤️ The sensor design itself is the [Proportional Sync Feedback Sensor by kashine6](https://github.com/kashine6/Proportional-Sync-Feedback-Sensor).

## Which Qidi printers

The Plus4 has a tension switch at the entrance to the heated chamber (stock firmware uses it as a tangle detector on `U_1:PC3`). Swapping it for a PFS gives Happy Hare proportional feedback instead of an on/off signal, for tighter syncing and more useful clog/tangle detection.

The Q2 and Max4 already ship with a hub-mounted tension sensor, but it is digital (a switch). That is good enough in practice — the gain from an analog sensor is not very important — so a PFS is more of a nice-to-have there. You can still fit one, but you will have to source your own ADC pin and mount.

## Requirements

- The PFS kit. Easiest is the [AliExpress kit](https://pl.aliexpress.com/item/1005010470743517.html) (Hall sensor, magnet, spring, hardware); or source the parts from the [original repo](https://github.com/kashine6/Proportional-Sync-Feedback-Sensor).
- The printed parts in [`./3D files/`](./3D%20files/) — `sensor-body`, `body-cap`, `piston` and `mounting-plate`. See [`assembly.png`](./3D%20files/assembly.png).
- A soldering iron. The PFS board ships connector, so you will either solder a connector onto it or solder the printer's sensor cable straight to the board (see [Wiring](#2-wiring)).
- Optional: a crimping tool and matching connector, if you would rather crimp the cable than solder to it.
- A little glue or resin to secure the board and provide strain relief.

## Hardware installation (Qidi Plus4)

### 1. Open the printer and remove the stock tension sensor

The stock sensor lives inside the heated chamber, at the point where the PTFE tube enters it. To reach it you have to take off the top plastic panel:

1. Remove the glass top.
2. Undo the 5 screws below the foam on the top panel. On older Plus4 units the foam may completely cover these screws — feel for the holes with something small (e.g. a hex key), then carefully slit the foam over each hole with a razor.
3. Undo the 4 screws holding the handles down.
4. Lift the top panel off and undo the 2 screws holding down the stock tension switch.
5. Disconnect or cut the cable on the stock tension switch.

Plus4 top panel removed, showing the handle and cover screws

### 2. Wiring

You can reuse the stock sensor's cable — it already carries everything the PFS needs: +5 V, GND and the signal on `U_1:PC3` (an ADC-capable pin on the toolhead MCU, the same pin the stock tangle switch used). How you connect depends on your unit, so identify your stock cable before you cut anything.

Newer Plus4 units have a cable that ends in a removable connector, and it should be possible to mate it with the PFS board and run the sensor without modifying the cable at all.

> [!WARNING]
> This is unconfirmed — please verify and report back! Nobody has yet confirmed that the connector and its pin order actually match the PFS board on a new unit. Check the pinout against the table below before powering on (a reversed +5 V / GND can kill the Hall sensor), then let us know what you find — open an issue or ping us on Discord so we can document it properly.

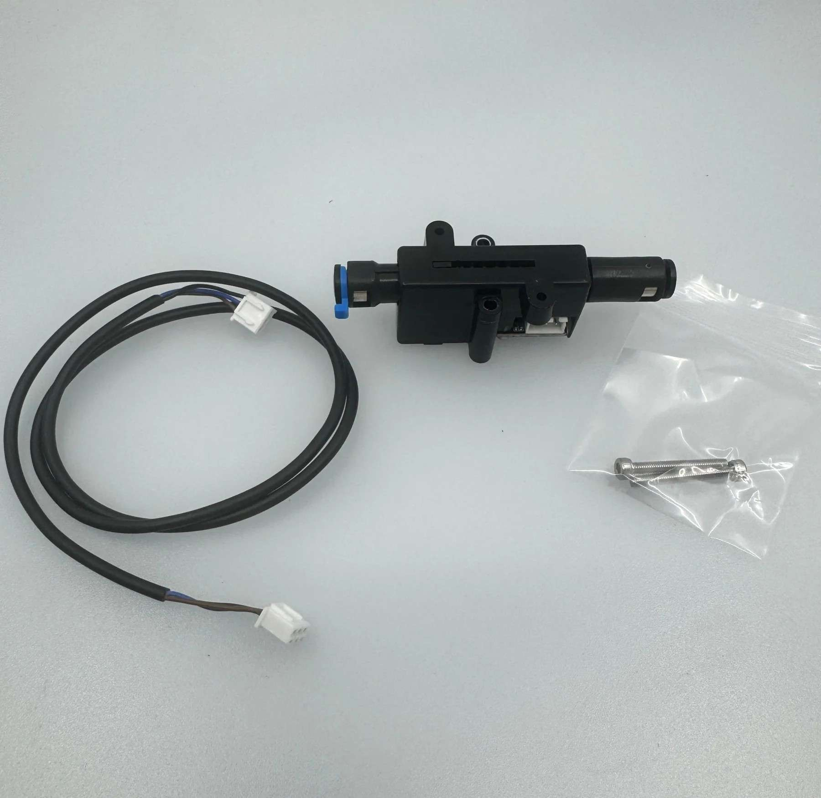
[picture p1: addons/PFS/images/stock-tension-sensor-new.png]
Newer Plus4 stock tension sensor with a detachable connector


Older Plus4 units have a cable with no detachable connector. Cut it, strip the wires, and either crimp on a PFS connector or solder the wires straight to the PFS board.

Older Plus4 stock tension sensor with a hardwired cable

Pin and colour mapping (both cases):

| PFS pin | Signal | Stock cable wire |
|---|---|---|
| top | +5 V | brown |
| middle  | GND | blue |
| bottom  | SIG | black |

> [!WARNING]
> Wire colours could vary between batches — verify against your own cable before powering on. Swapping +5 V and GND can damage the Hall sensor.

### 3. Mounting & orientation

Orient the long neck towards the extruder; the spring naturally pushes the plunger that way, which is what you want. The PFS does not need to be bolted down — gluing it in place, or even leaving it hanging in the filament path, works fine.

> [!WARNING]
> The original tension-sensor pocket is very tight and the PFS connector may not physically fit in it. The author got it in by soldering the wires directly to the board (no connector) and securing it with a blob of resin for strain relief. If you mount the PFS anywhere other than the stock pocket, space is not a problem.

> [!NOTE]
> The printed enclosure was meant to drop into the stock pocket and reuse the original tension-sensor screw holes, but it does not fit well enough to use them. A redesign is planned — not a big deal, since the PFS does not need to be bolted down anyway.

PFS installed at the chamber entrance, long neck toward the extruder

## Software configuration

All paths below are relative to your printer's config directory (`~/printer_data/config/`).

### 1. `printer.cfg` — remove the stock sensor on `PC3`

A pin can only belong to one object, so delete (or comment out) the stock tangle switch, and any other section that claims `PC3`:

```diff
-[filament_switch_sensor fila]
-pause_on_runout: True
-runout_gcode:
-    M118 Filament tangle detected
-event_delay: 3.0
-pause_delay: 0.5
-switch_pin:U_1:PC3
```

### 2. `mmu/base/mmu_hardware.cfg` — declare the analog pin

In the `[mmu_sensors]` section, add the PFS. Start with the default scaling values; the real ones come from calibration in the next section.

```ini
[mmu_sensors]
# ... existing pre_gate / gate / extruder sensors stay as they are ...

sync_feedback_analog_pin: U_1:PC3        # ADC pin the PFS signal is wired to
sync_feedback_analog_max_compression: 1  # placeholder — set by MMU_CALIBRATE_PSENSOR
sync_feedback_analog_max_tension: 0      # placeholder — set by MMU_CALIBRATE_PSENSOR
sync_feedback_analog_neutral_point: 0.50 # placeholder — set by MMU_CALIBRATE_PSENSOR
```

### 3. `mmu/base/mmu_parameters.cfg` — enable sync feedback

```diff
-sync_feedback_enabled: 0
+sync_feedback_enabled: 1
```

Set the buffer travel to the physical plunger travel of the PFS (≈ 14.5 mm). `buffer_maxrange` also matters for calibration — it is the distance `MMU_CALIBRATE_PSENSOR` sweeps by default.

```ini
sync_feedback_buffer_range: 14.5     # PFS plunger travel (mm)
sync_feedback_buffer_maxrange: 14.5  # absolute end-to-end travel (mm)
sync_feedback_speed_multiplier: 5    # leave at defaults
sync_feedback_boost_multiplier: 3
sync_feedback_extrude_threshold: 5
```

Restart Klipper so the new sensor is picked up.

## Calibration

This follows the [Happy Hare proportional-sensor procedure](https://github.com/moggieuk/Happy-Hare/wiki/Synchronized-Gear-Extruder#---sync-feedback-sensor-options).

### Step 1 — sanity-check the sensor

With the placeholder values from above and Klipper restarted, run `MMU_QUERY_PSENSOR`. It prints something like:

```
PSENSOR Enabled: True  Value: 0.014  Raw Value: 0.538
```

Raw Value is the bare ADC reading (0 – 1); Value is the normalised feedback (−1 tension … +1 compression). Push and pull the plunger by hand (or jog the gear) and watch Raw Value sweep across most of the 0 – 1 range (roughly ~0.004 at one extreme to ~0.99 at the other). If it barely moves or stays pinned, your wiring or the ADC pin is wrong — fix that before calibrating.

### Step 2 — auto-calibrate

Load filament first (`MMU_LOAD`, or select a gate) — calibration refuses to run on an empty MMU or the bypass. Then run `MMU_CALIBRATE_PSENSOR`. Happy Hare drives the gear stepper in 2 mm increments in both directions, finds the compression and tension extremes, and prints recommended settings, e.g.:

```
[mmu_sensors]
sync_feedback_analog_max_compression: 0.0797
sync_feedback_analog_max_tension:     1.0000
sync_feedback_analog_neutral_point:   0.5398
```

Polarity depends on your wiring and orientation, so don't assume `max_compression` is the larger number — in the example above it is the smaller one. Just copy whatever the command reports; `neutral_point` is simply the midpoint of the two extremes.

We normally run the PFS as a symmetrical sensor: you want the plunger sitting around its mid point so neutral tension is in the centre of the sensing range. Calibrating from the middle and using the auto-set `neutral_point` is what gives you that.

> [!TIP]
> If calibration fails to find both limits, the plunger is probably already too tensioned or too compressed at the start. Nudge it back to roughly the middle of its range with small `MMU_TEST_MOVE MOVE=<mm>` moves (positive and negative values move the filament in opposite directions), watching the plunger position in the Happy Hare panel in Fluidd/Mainsail, then run the calibration again. You can also sweep further with `MMU_CALIBRATE_PSENSOR MOVE=<mm>` (1–100).

### Step 3 — apply

Copy the three reported values into `[mmu_sensors]` in `mmu_hardware.cfg`, replacing the placeholders from configuration step 2, and restart Klipper.

## Tuning notes

- Weaker spring, shorter travel. The PFS spring is softer and its travel is smaller than the stock Plus4 tension sensor. If you cut tips (Qidi's cutter sits before the extruder), the filament-tensioning move during a cut may now over- or under-tension. Re-check `variable_tension_length` in `mmu/mmu_macro_vars.cfg` → `[gcode_macro _MMU_CUT_TIP_VARS]` (default `15.0`) and adjust if cuts get worse after the swap.
- FlowGuard sensitivity. Proportional sensors can run a lower `flowguard_max_relief` than switch-based ones. Start at the shipped default, lower it for a more sensitive clog/tangle trigger, and raise it if you get false positives.

## References

- [Happy Hare — Synchronized Gear/Extruder & sync-feedback sensors](https://github.com/moggieuk/Happy-Hare/wiki/Synchronized-Gear-Extruder#---sync-feedback-sensor-options)
- [Proportional Sync Feedback Sensor (original repo, kashine6)](https://github.com/kashine6/Proportional-Sync-Feedback-Sensor)
- [PFS kit on AliExpress](https://pl.aliexpress.com/item/1005010470743517.html)

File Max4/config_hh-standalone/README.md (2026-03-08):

# STANDALONE HAPPY HARE

The goal of this config is to have a configuration that uses Happy Hare as much as possible. In this way we have access to all the advanced features of Happy Hare and can configure the printer to our liking via mmu configuration files.

>[!WARNING]
>Gcodes for this config differ from Qidi's stock box gcode. Do not use old Qidi Box gcodes or the stock Qidi slicer profile!

## STATUS

Not yet tested!

Known issues:
- none!

Report new issues via the Github "Issues" tab.

## INSTALLATION

1. Replace your bunnybox_macros.cfg with the one in this folder.

2. Replace your mmu folder with the one in this folder.

3. In the slicer, set your profile to use the machine gcodes [following g-codes](slicer_machine_gcodes_hh.md)

4. Make sure your gcode_macros.cfg follows the following rule (in addition to the common changes made during installation):

    * nothing that requires filament happens in PRINT_START

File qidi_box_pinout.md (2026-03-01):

# Qidi Box Pinout (Reverse Engineered from v1)

The Qidi Box uses the [STM32F402RCT6](https://www.st.com/resource/en/datasheet/stm32f401cc.pdf) microcontroller.

**Note:** The stepper motor drivers (TMC2009) are not connected by UART, the configuration is done via resistors. UART connection requires reworking the board (soldering of 0402 resistors, tightly packed) and is thus not recommended.

| No | Pin \ Slot | Function | Comment |
| :--- | :--- | :--- | :--- |
| 1 | VBAT | VBAT | |
| 2 | PC13 | STEP | |
| 3 | PC14 | DIR | |
| 4 | PC15 | nEN | |
| 5 | OSC_IN | osc_in | 8 MHz quartz |
| 6 | OSC_OUT | osc_out | 8 MHz quartz |
| 7 | NRST | nRST | |
| 8 | PC0 | nEN | |
| 9 | PC1 | Temp1_Ain | NTC 100K MGB18-104F39050L32 |
| 10 | PC2 | Temp2_Ain | NTC 100K MGB18-104F39050L32 |
| 11 | PC3 | | |
| 12 | VSSA | VSS | |
| 13 | VDDA | VDD | |
| 14 | PA0 | RUNOUT | |
| 15 | PA1 | WHITE | |
| 16 | PA2 | RED | |
| 17 | PA3 | Heater | Sensor AHT20_F over i2c |
| 18 | VSS | VSS | |
| 19 | VDD | VDD | |
| 20 | PA4 | HeaterFanA | |
| 21 | PA5 | HeaterFanB | |
| 22 | PA6 | Board fan | |
| 23 | PA7 | RUNOUT | |
| 24 | PC4 | WHITE | |
| 25 | PC5 | RED | |
| 26 | PB0 | Motion sensor | |
| 27 | PB1 | B button | ? IDK what this is - might be for daisy chaining boxes (to share hub endstop) |
| 28 | PB2 | DIR | |
| 29 | PB10 | | |
| 30 | VCAP_1 | VCAP | |
| 31 | VSS | VSS | |
| 32 | VDD | VDD | |
| 33 | PB12 | | |
| 34 | PB13 | SPI2_SCK | Used for RFID |
| 35 | PB14 | SPI2_MISO | Used for RFID |
| 36 | PB15 | SPI2_MOSI | Used for RFID |
| 37 | PC6 | RFID1_CS | |
| 38 | PC7 | RFID2_CS | |
| 39 | PC8 | STEP | |
| 40 | PC9 | I2C3_SDA | |
| 41 | PA8 | I2C3_SCL | |
| 42 | PA9 | B endstop | Connected to PA10 with 1k. Stepper driver UART TX (unconnected, requires board rework) |
| 43 | PA10 | E endstop | Connected to PA9 with 1k. Stepper driver UART TX (unconnected, requires board rework) |
| 44 | PA11 | USB | |
| 45 | PA12 | USB | |
| 46 | PA13 | RUNOUT | |
| 47 | VSS | VSS | |
| 48 | VDD | VDD | |
| 49 | PA14 | WHITE | |
| 50 | PA15 | RED | |
| 51 | PC10 | nEN | |
| 52 | PC11 | DIR | |
| 53 | PC12 | STEP | |
| 54 | PD2 | EN | |
| 55 | PB3 | RUNOUT | |
| 56 | PB4 | WHITE | |
| 57 | PB5 | RED | |
| 58 | PB6 | | |
| 59 | PB7 | | |
| 60 | BOOT0 | BOOT0 | |
| 61 | PB8 | DIR | |
| 62 | PB9 | STEP | |
| 63 | VSS | VSS | |
| 64 | VDD | VDD | |

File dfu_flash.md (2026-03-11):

# Flashing the Qidi Box

## Flashing Katapult on the Qidi Box

1. Build katapult

    ```
    cd ~/katapult
    make menuconfig
    ```
    Make sure your menuconfig matches this:

    

    ```
    make clean
    make -j4
    ```

2. Make sure the klipper service stopped

    ```
    sudo service klipper stop
    ```

3. Put MCU into DFU mode

    ```
    cd ~/katapult/scripts/
    python3 flashtool.py -d /dev/serial/by-id/usb-Klipper_QIDI_BOX_V1_1.1.1_56003A001051353033353536-if00 -b 500000 -r
    Connecting to Serial Device /dev/serial/by-id/usb-Klipper_QIDI_BOX_V1_1.1.1_56003A001051353033353536-if00, baud 500000
    Detected USB device running Klipper
    Requesting USB bootloader for /dev/serial/by-id/usb-Klipper_QIDI_BOX_V1_1.1.1_56003A001051353033353536-if00...
    Waiting for USB Reconnect...done
    Detected new USB Device: 0483:5740 mks color boot
    Device is not Katapult, exiting...
    Bootloader Request Complete
    ```

4. Check if MCU into DFU mode

    ```
    lsusb
    Bus 002 Device 006: ID 0483:df11 STMicroelectronics STM Device in DFU Mode
    ```

5. Flash katapult:

    ```
    sudo dfu-util -R -a 0 -s 0x08000000:mass-erase:force:leave -D ~/katapult/out/katapult.bin -d 0483:df11

    ```

    You should see a successful flash like this:

    <!-- ![image](doc/images/mmu-mcu-katapult-flash-success.png) -->

    ```
    Copyright 2005-2009 Weston Schmidt, Harald Welte and OpenMoko Inc.
    Copyright 2010-2021 Tormod Volden and Stefan Schmidt
    This program is Free Software and has ABSOLUTELY NO WARRANTY
    Please report bugs to http://sourceforge.net/p/dfu-util/tickets/

    dfu-util: Warning: Invalid DFU suffix signature
    dfu-util: A valid DFU suffix will be required in a future dfu-util release
    Opening DFU capable USB device...
    Device ID 0483:df11
    Device DFU version 011a
    Claiming USB DFU Interface...
    Setting Alternate Interface #0 ...
    Determining device status...
    DFU state(10) = dfuERROR, status(10) = Device's firmware is corrupt. It cannot return to run-time (non-DFU) operations
    Clearing status
    Determining device status...
    DFU state(2) = dfuIDLE, status(0) = No error condition is present
    DFU mode device DFU version 011a
    Device returned transfer size 2048
    DfuSe interface name: "Internal Flash  "
    Performing mass erase, this can take a moment
    Setting timeout to 35 seconds
    Downloading element to address = 0x08000000, size = 4980
    Erase           [=========================] 100%         4980 bytes
    Erase    done.
    Download        [=========================] 100%         4980 bytes
    Download done.
    File downloaded successfully
    Submitting leave request...
    Transitioning to dfuMANIFEST state
    dfu-util: can't detach
    Resetting USB to switch back to Run-Time mode
    ```

## Flashing Klipper on the Qidi Box

1. Build klipper

    ```
    cd ~/klipper
    make menuconfig
    ```
    Make sure your menuconfig matches this:

    <!-- ![image](doc/images/mmu-mcu-klipper-menuconfig.png) -->

    ```
    make clean
    make -j4
    ```

2. Make sure the klipper service stopped

    ```
    sudo service klipper stop
    ```

3. Get device name:

    ```
    ls -all /dev/serial/by-id/
    lrwxrwxrwx 1 root root 13 Feb  8 10:49 usb-katapult_stm32f401xc_56003A001051353033353536-if00 -> ../../ttyACM1

4. Flash klipper:

    ```
    cd ~/katapult/scripts
    python3 flashtool.py -b 500000 -d /dev/ttyACM1 -f ~/klipper/out/klipper.bin
    ```
    You should see a successful flash like this:

    <!-- ![image](doc/images/mmu-mcu-klipper-flash-success.png) --> 

    ```
    Connecting to Serial Device /dev/ttyACM1, baud 500000
    Detected USB device running Katapult
    Detected Klipper binary version v2026.02.00-0-gc70d21ab-dirty-20260207_161419-mkspi, MCU: stm32f401xc
    Attempting to connect to bootloader
    Katapult Connected
    Software Version: v0.0.1-110-gb0bf421
    Protocol Version: 1.1.0
    Block Size: 64 bytes
    Application Start: 0x8008000
    MCU type: stm32f401xc
    Flashing '/home/mks/klipper/out/klipper.bin'...

    [##################################################]

    Write complete: 3 pages
    Verifying (block count = 575)...

    [##################################################]

    Verification Complete: SHA = 676832F629B1902388F24738047FA78BE9F9F047
    Programming Complete
    ```

5. Get device name:

    ```
    ls -all /dev/serial/by-id/
    usb-Klipper_stm32f401xc_56003A001051353033353536-if00 -> ../../ttyACM1

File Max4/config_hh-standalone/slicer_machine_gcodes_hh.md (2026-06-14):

<p align="center">
  <h1 align="center"> Max4 Happy Hare Standalone Slicer Machine G-Codes</h1>
</p>

# MACHINE START G-CODE

Possible to modify - the general idea is:
```
*****CONCEPTUAL - DO NOT COPY WITHOUT MODIFICATION*****

MMU_START_SETUP INITIAL_TOOL={initial_tool} TOTAL_TOOLCHANGES=!total_toolchanges! REFERENCED_TOOLS=!referenced_tools! TOOL_COLORS=!colors! TOOL_TEMPS=!temperatures! TOOL_MATERIALS=!materials! FILAMENT_NAMES=!filament_names! PURGE_VOLUMES=!purge_volumes!
MMU_START_CHECK

; your homing, preheating, leveling, etc goes here
; nothing that requires filament in the extruder though!

MMU_START_LOAD_INITIAL_TOOL

; your purging logic goes here

SET_PRINT_STATS_INFO CURRENT_LAYER=1
SET_PRINT_STATS_INFO TOTAL_LAYER={total_layer_count}
```

The gcode below is a Qidi start g-code modified with Happy Hare (and thus can be copied into your slicer):
```
;===== HAPPY HARE SETUP =====
MMU_START_SETUP INITIAL_TOOL={initial_tool} TOTAL_TOOLCHANGES=!total_toolchanges! REFERENCED_TOOLS=!referenced_tools! TOOL_COLORS=!colors! TOOL_TEMPS=!temperatures! TOOL_MATERIALS=!materials! FILAMENT_NAMES=!filament_names! PURGE_VOLUMES=!purge_volumes!

;===== PRINT_PHASE_INIT =====
SET_PRINT_STATS_INFO TOTAL_LAYER=[total_layer_count]
SET_PRINT_MAIN_STATUS MAIN_STATUS=print_start
M220 S100
M221 S100
SET_INPUT_SHAPER SHAPER_TYPE_X=mzv
SET_INPUT_SHAPER SHAPER_TYPE_Y=mzv
DISABLE_ALL_SENSOR
M1002 R1
M107
CLEAR_PAUSE
M140 S[bed_temperature_initial_layer_single]
M141 S[chamber_temperatures]
G29.0
G28

;===== HAPPY HARE CHECK =====
MMU_START_CHECK

;===== PRINT_START =====
SET_PRINT_MAIN_STATUS MAIN_STATUS=printing
MMU_START_LOAD_INITIAL_TOOL
M140 S[bed_temperature_initial_layer_single]
M104 S[nozzle_temperature_initial_layer]
M141 S[chamber_temperatures]
G0 X195 Y1 F20000
G0 Z10 F480
G92 Z{10 - ((nozzle_temperature_initial_layer[initial_tool] - 130) / 14 - 5.0) / 100}
G4 P3000
probe samples=1
G91
G0 Z5 F480
G90
G1 X170 Y1 F20000
G91
G0 Z{initial_layer_print_height-5} F480
G90
G0 X190 E8 F{outer_wall_volumetric_speed/(24/20) * 60}
G0 X195 E.3742 F{outer_wall_volumetric_speed/(0.3*0.5)/4 * 60}
G0 X200 E.3742 F{outer_wall_volumetric_speed/(0.3*0.5) * 60}
G0 X205 E.3742 F{outer_wall_volumetric_speed/(0.3*0.5)/4 * 60}
G0 X210 E.3742 F{outer_wall_volumetric_speed/(0.3*0.5) * 60}
G0 X215 E.3742 F{outer_wall_volumetric_speed/(0.3*0.5)/4 * 60}
G91
G1 X1 Z{-1+initial_layer_print_height+0.1}
G1 X4
G1 Z1 F480
G1 X-50 Y1.5 F20000
G1 Z{1-initial_layer_print_height-0.1} F480
G90
G0 X190 E10 F{outer_wall_volumetric_speed/(24/20) * 60}
G0 X195 E.3742 F{outer_wall_volumetric_speed/(0.3*0.5)/4 * 60}
G0 X200 E.3742 F{outer_wall_volumetric_speed/(0.3*0.5) * 60}
G0 X205 E.3742 F{outer_wall_volumetric_speed/(0.3*0.5)/4 * 60}
G0 X210 E.3742 F{outer_wall_volumetric_speed/(0.3*0.5) * 60}
G0 X215 E.3742 F{outer_wall_volumetric_speed/(0.3*0.5)/4 * 60}
G91
G1 X1 Z{-initial_layer_print_height-0.1}
G1 X4
G1 Z1 F480
G90
```

# MACHINE END G-CODE
```
MMU_END
DISABLE_BOX_HEATER
M141 S0
M140 S0
DISABLE_ALL_SENSOR
G1 E-3 F1800
G0 Z{max_layer_z + 3} F600
G0 Y380 F12000
G0 X128 Y380 F12000
{if max_layer_z < max_print_height / 2}G1 Z{max_print_height / 2 + 10} F600{else}G1 Z{min(max_print_height, max_layer_z + 3)}{endif}
M104 S0
PRINT_END
```
# BEFORE LAYER CHANGE G-CODE
```
;BEFORE_LAYER_CHANGE
;[layer_z]
G92 E0
```

# LAYER CHANGE G-CODE
```
{if timelapse_type == 1} ; timelapse with wipe tower
G92 E0
G1 E-[retraction_length] F1800
G2 Z{layer_z + 0.4} I0.86 J0.86 P1 F20000 ; spiral lift a little
BOX_MOVE_TO_TRASH
{if layer_z <=25}
G1 Z25
{endif}
G92 E0
M400
TIMELAPSE_TAKE_FRAME
G1 E[retraction_length] F300
G1 X180 F8000
G1 Y380
{if layer_z <=25}
G1 Z[layer_z]
{endif}
{elsif timelapse_type == 0} ; timelapse without wipe tower
TIMELAPSE_TAKE_FRAME
{endif}
_MMU_UPDATE_HEIGHT HEIGHT={layer_z}
G92 E0
SET_PRINT_STATS_INFO CURRENT_LAYER={layer_num + 1}
```

# TIME LAPSE G-CODE
```
TIMELAPSE_TAKE_FRAME
```

# CHANGE FILAMENT G-CODE
```
T[next_extruder]
```

# CHANGE EXTRUSION ROLE G-CODE
```

```

# PAUSE G-CODE
```
M0
```

# TEMPLATE CUSTOM G-CODE
```

```

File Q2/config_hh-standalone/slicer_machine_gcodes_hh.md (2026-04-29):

<p align="center">
  <h1 align="center"> Q2 Happy Hare Standalone Slicer Machine G-Codes</h1>
</p>

# MACHINE START G-CODE

Possible to modify - the general idea is:
```
*****CONCEPTUAL - DO NOT COPY WITHOUT MODIFICATION*****

MMU_START_SETUP INITIAL_TOOL={initial_tool} TOTAL_TOOLCHANGES=!total_toolchanges! REFERENCED_TOOLS=!referenced_tools! TOOL_COLORS=!colors! TOOL_TEMPS=!temperatures! TOOL_MATERIALS=!materials! FILAMENT_NAMES=!filament_names! PURGE_VOLUMES=!purge_volumes!
MMU_START_CHECK

; your homing, preheating, leveling, etc goes here
; nothing that requires filament in the extruder though!

MMU_START_LOAD_INITIAL_TOOL

; your purging logic goes here

SET_PRINT_STATS_INFO CURRENT_LAYER=1
SET_PRINT_STATS_INFO TOTAL_LAYER={total_layer_count}
```

The gcode below is a Qidi start g-code modified with Happy Hare (and thus can be copied into your slicer):
```
;===== HAPPY HARE SETUP =====
MMU_START_SETUP INITIAL_TOOL={initial_tool} TOTAL_TOOLCHANGES=!total_toolchanges! REFERENCED_TOOLS=!referenced_tools! TOOL_COLORS=!colors! TOOL_TEMPS=!temperatures! TOOL_MATERIALS=!materials! FILAMENT_NAMES=!filament_names! PURGE_VOLUMES=!purge_volumes!
MMU_START_CHECK

;===== QIDI PRINT START AND PREHEAT =====
; NOTE: no purging allowed in print start
PRINT_START BED=[bed_temperature_initial_layer_single] HOTEND=[nozzle_temperature_initial_layer] CHAMBER=[chamber_temperature] EXTRUDER=[initial_no_support_extruder]
SET_PRINT_STATS_INFO TOTAL_LAYER=[total_layer_count]
M83
M140 S[bed_temperature_initial_layer_single]
M104 S[nozzle_temperature_initial_layer]
M141 S[chamber_temperature]
G4 P3000

;===== HAPPY HARE LOAD INITIAL TOOL =====
MMU_START_LOAD_INITIAL_TOOL

;===== QIDI PURGE SEQUENCE =====
G1 X108.000 Y1 F30000
G0 Z[initial_layer_print_height] F600
;G1 E3 F1800
G90
M83
G0 X128 E8  F{outer_wall_volumetric_speed/(24/20)    * 60}
G0 X133 E.3742  F{outer_wall_volumetric_speed/(0.3*0.5)/4     * 60}
G0 X138 E.3742  F{outer_wall_volumetric_speed/(0.3*0.5)     * 60}
G0 X143 E.3742  F{outer_wall_volumetric_speed/(0.3*0.5)/4     * 60}
G0 X148 E.3742  F{outer_wall_volumetric_speed/(0.3*0.5)     * 60}
G0 X153 E.3742  F{outer_wall_volumetric_speed/(0.3*0.5)/4     * 60}
G91
G1 X1 Z-0.300
G1 X4
G1 Z1 F1200
G90
M400
G1 X108.000 Y2.5 F30000
G0 Z[initial_layer_print_height] F600
M83
G0 X128 E10  F{outer_wall_volumetric_speed/(24/20)    * 60}
G0 X133 E.3742  F{outer_wall_volumetric_speed/(0.3*0.5)/4     * 60}
G0 X138 E.3742  F{outer_wall_volumetric_speed/(0.3*0.5)     * 60}
G0 X143 E.3742  F{outer_wall_volumetric_speed/(0.3*0.5)/4     * 60}
G0 X148 E.3742  F{outer_wall_volumetric_speed/(0.3*0.5)     * 60}
G0 X153 E.3742  F{outer_wall_volumetric_speed/(0.3*0.5)/4     * 60}
G91
G1 X1 Z-0.300
G1 X4
G1 Z1 F1200
G90
M400
G1 Z1 F600

```

# MACHINE END G-CODE
```
MMU_END
DISABLE_BOX_HEATER
M141 S0
M140 S0
DISABLE_ALL_SENSOR
G1 E-3 F1800
G0 Z{max_layer_z + 3} F600
G0 Y270 F12000
G0 X90 Y270 F12000
{if max_layer_z < max_print_height / 2}G1 Z{max_print_height / 2 + 10} F600{else}G1 Z{min(max_print_height, max_layer_z + 3)}{endif}
M104 S0
```
# BEFORE LAYER CHANGE G-CODE
```

```

# LAYER CHANGE G-CODE
```
{if timelapse_type == 1} ; timelapse with wipe tower
G92 E0
G1 E-[retraction_length] F1800
G2 Z{layer_z + 0.4} I0.86 J0.86 P1 F20000 ; spiral lift a little
G1 Y235 F20000
G1 X97 F20000
{if layer_z <=25}
G1 Z25
{endif}
G1 Y254 F2000
G92 E0
M400
TIMELAPSE_TAKE_FRAME
G1 E[retraction_length] F300
G1 X85 F2000
G1 X97 F2000
G1 Y220 F2000
{if layer_z <=25}
G1 Z[layer_z]
{endif}
{elsif timelapse_type == 0} ; timelapse without wipe tower
TIMELAPSE_TAKE_FRAME
{endif}
_MMU_UPDATE_HEIGHT HEIGHT={layer_num + 1} 
G92 E0
SET_PRINT_STATS_INFO CURRENT_LAYER={layer_num + 1}
```

# TIME LAPSE G-CODE
```
TIMELAPSE_TAKE_FRAME
```

# CHANGE FILAMENT G-CODE
```
T[next_extruder]
```

# CHANGE EXTRUSION ROLE G-CODE
```

```

# PAUSE G-CODE
```
M0
```

# TEMPLATE CUSTOM G-CODE
```

```

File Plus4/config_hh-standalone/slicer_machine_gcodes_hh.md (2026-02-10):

# MACHINE START G-CODE

Possible to modify - the general idea is:
```
*****CONCEPTUAL - DO NOT COPY WITHOUT MODIFICATION*****

MMU_START_SETUP INITIAL_TOOL={initial_tool} TOTAL_TOOLCHANGES=!total_toolchanges! REFERENCED_TOOLS=!referenced_tools! TOOL_COLORS=!colors! TOOL_TEMPS=!temperatures! TOOL_MATERIALS=!materials! FILAMENT_NAMES=!filament_names! PURGE_VOLUMES=!purge_volumes!
MMU_START_CHECK

; your homing, preheating, leveling, etc goes here
; nothing that requires filament in the extruder though!

MMU_START_LOAD_INITIAL_TOOL

; your purging logic goes here

SET_PRINT_STATS_INFO CURRENT_LAYER=1
SET_PRINT_STATS_INFO TOTAL_LAYER={total_layer_count}
```

```
MMU_START_SETUP INITIAL_TOOL={initial_tool} TOTAL_TOOLCHANGES=!total_toolchanges! REFERENCED_TOOLS=!referenced_tools! TOOL_COLORS=!colors! TOOL_TEMPS=!temperatures! TOOL_MATERIALS=!materials! FILAMENT_NAMES=!filament_names! PURGE_VOLUMES=!purge_volumes!
MMU_START_CHECK
PRINT_START BED=[bed_temperature_initial_layer_single] HOTEND=[nozzle_temperature_initial_layer] CHAMBER=[chamber_temperature] EXTRUDER=[initial_no_support_extruder]
SET_PRINT_STATS_INFO TOTAL_LAYER=[total_layer_count]
M83
MMU_START_LOAD_INITIAL_TOOL
M140 S[bed_temperature_initial_layer_single]
M104 S[nozzle_temperature_initial_layer]
M141 S[chamber_temperature]
G4 P3000
G0 X{max((min(print_bed_max[0] - 12, first_layer_print_min[0] + 80) - 85), 0)} Y{max((min(print_bed_max[1] - 3, first_layer_print_min[1] + 80) - 85), 0)} Z5 F6000
G0 Z[initial_layer_print_height] F600
G1 E3 F1800
;Qidi purge line
G1 X{(min(print_bed_max[0] - 12, first_layer_print_min[0] + 80))} E{85 * 0.5 * initial_layer_print_height * nozzle_diameter[0]} F3000
G1 Y{max((min(print_bed_max[1] - 3, first_layer_print_min[1] + 80) - 85), 0) + 2} E{2 * 0.5 * initial_layer_print_height * nozzle_diameter[0]} F3000
G1 X{max((min(print_bed_max[0] - 12, first_layer_print_min[0] + 80) - 85), 0)} E{85 * 0.5 * initial_layer_print_height * nozzle_diameter[0]} F3000
G1 Y{max((min(print_bed_max[1] - 3, first_layer_print_min[1] + 80) - 85), 0) + 85} E{83 * 0.5 * initial_layer_print_height * nozzle_diameter[0]} F3000
G1 X{max((min(print_bed_max[0] - 12, first_layer_print_min[0] + 80) - 85), 0) + 2} E{2 * 0.5 * initial_layer_print_height * nozzle_diameter[0]} F3000
G1 Y{max((min(print_bed_max[1] - 3, first_layer_print_min[1] + 80) - 85), 0) + 3} E{82 * 0.5 * initial_layer_print_height * nozzle_diameter[0]} F3000
G1 X{max((min(print_bed_max[0] - 12, first_layer_print_min[0] + 80) - 85), 0) + 3} Z0
G1 X{max((min(print_bed_max[0] - 12, first_layer_print_min[0] + 80) - 85), 0) + 6}
;Alternatively use KAMP purge line
;LINE_PURGE
G1 Z1 F600
SET_PRINT_STATS_INFO CURRENT_LAYER=1
SET_PRINT_STATS_INFO TOTAL_LAYER={total_layer_count}
```

# MACHINE END G-CODE
```
MMU_END
DISABLE_BOX_HEATER
M141 S0
M140 S0
DISABLE_ALL_SENSOR
G1 E-3 F1800
G0 Z{max_layer_z + 3} F600
G0 Y290 F12000
G0 X90 Y290 F12000
{if max_layer_z < max_print_height / 2}G1 Z{max_print_height / 2 + 10} F600{else}G1 Z{min(max_print_height, max_layer_z + 3)}{endif}
M104 S0
```
# BEFORE LAYER CHANGE G-CODE
```
;BEFORE_LAYER_CHANGE
;[layer_z]
G92 E0
```

# LAYER CHANGE G-CODE
```
{if timelapse_type == 1} ; timelapse with wipe tower
G92 E0
G1 E-[retraction_length] F1800
G2 Z{layer_z + 0.4} I0.86 J0.86 P1 F20000 ; spiral lift a little
G1 Y304 F20000
G1 X95 F20000
G92 E0
M400
TIMELAPSE_TAKE_FRAME
G1 Y324 F5000
G1 E[retraction_length] F300
G1 X65 F5000
G1 Y290 F20000
{elsif timelapse_type == 0} ; timelapse without wipe tower
TIMELAPSE_TAKE_FRAME
{endif}
_MMU_UPDATE_HEIGHT HEIGHT={layer_num + 1} 
G92 E0
SET_PRINT_STATS_INFO CURRENT_LAYER={layer_num + 1}
```

# TIME LAPSE G-CODE
```
TIMELAPSE_TAKE_FRAME
```

# CHANGE FILAMENT G-CODE
```
T[next_extruder]
```

# CHANGE EXTRUSION ROLE G-CODE
```

```

# PAUSE G-CODE
```
M0
```

# TEMPLATE CUSTOM G-CODE
```

```

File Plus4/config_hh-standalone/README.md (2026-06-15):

# STANDALONE HAPPY HARE

The goal of this config is to have a configuration that uses Happy Hare as much as possible. In this way we have access to all the advanced features of Happy Hare and can configure the printer to our liking via mmu configuration files.

>[!WARNING]
>Gcodes for this config differ from Qidi's stock box gcode. Do not use old Qidi Box gcodes or the stock Qidi slicer profile!

## STATUS

Working - issues should be minor.

Known issues:
- none!

Report new issues via the Github "Issues" tab.

## ABOUT THESE FILES (maintainers)

At install time the Bunny Box installer copies this `mmu/` tree, then runs Happy
Hare's `install.sh` in upgrade mode. That installer **owns most of these files**:

* `mmu_cut_tip.cfg`, `mmu_form_tip.cfg`, `mmu_sequence.cfg`, `mmu_purge.cfg`,
  `mmu_leds.cfg`, `mmu_software.cfg`, `mmu_state.cfg`, `optional/*.cfg` — replaced
  with **symlinks** into `~/Happy-Hare`. The copies here are reference mirrors of
  the Happy Hare fork and are **not** the live config. Any Qidi-specific change to
  this logic must go into the [Happy Hare fork](https://github.com/Wazzup77/Happy-Hare)
  (`bunnybox` branch) — editing it here does nothing. Keep them in sync with the
  fork so the repo isn't misleading.
* `mmu_parameters.cfg`, `mmu_macro_vars.cfg`, `addons/*.cfg` (non-`_hw`) — Happy
  Hare re-templates these but **carries your values forward**, so the *values*
  here act as install-time defaults.

Bunny Box genuinely owns (Happy Hare leaves them frozen): `mmu_hardware.cfg`,
`mmu.cfg`, `addons/*_hw.cfg`, and the top-level `bunnybox_macros.cfg`. These are
the files the installer's smart-update 3-way-merges on re-install.

## INSTALLATION

1. Replace your bunnybox_macros.cfg with the one in this folder.

2. Replace your mmu folder with the one in this folder.

3. In the slicer, set your profile to use the machine gcodes [following g-codes](slicer_machine_gcodes_hh.md)

4. Make sure your gcode_macros.cfg follows the following rule (in addition to the common changes made during installation):

    * nothing that requires filament happens in PRINT_START

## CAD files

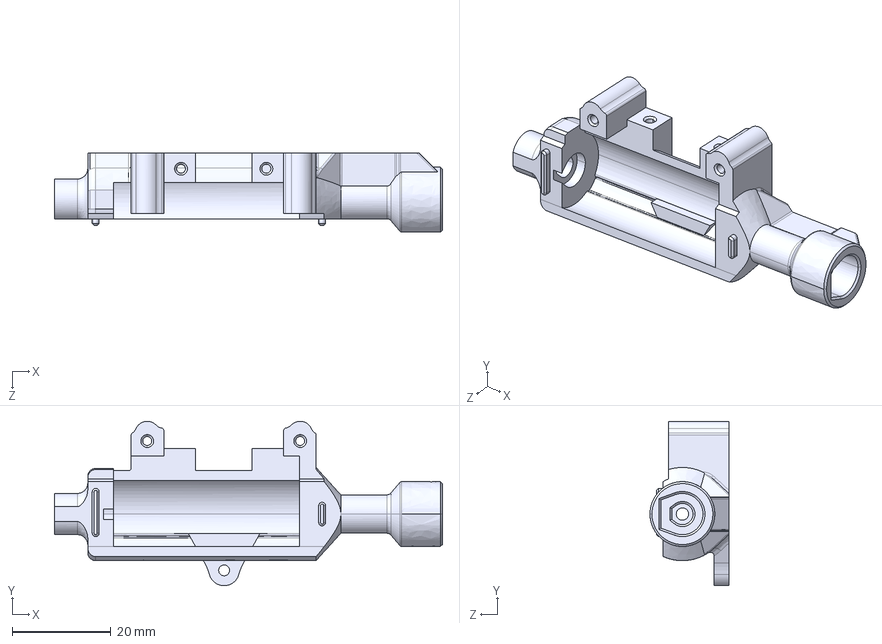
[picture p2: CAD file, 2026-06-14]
addons/PFS/3D files/sensor-body.STEP
78.6 x 33.3 x 16.0 mm

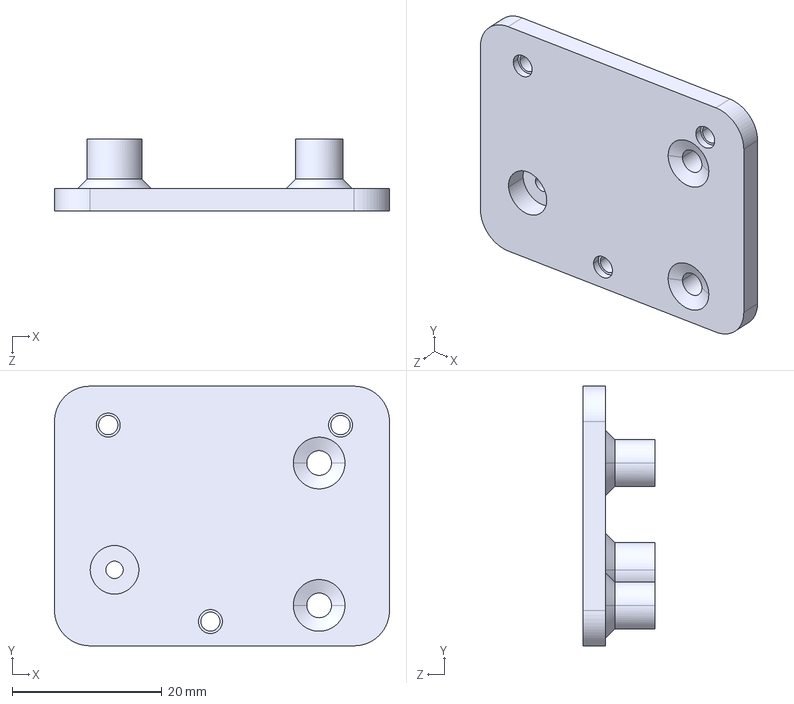
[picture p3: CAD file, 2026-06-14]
addons/PFS/3D files/mounting-plate.STEP
44.7 x 34.6 x 9.65 mm

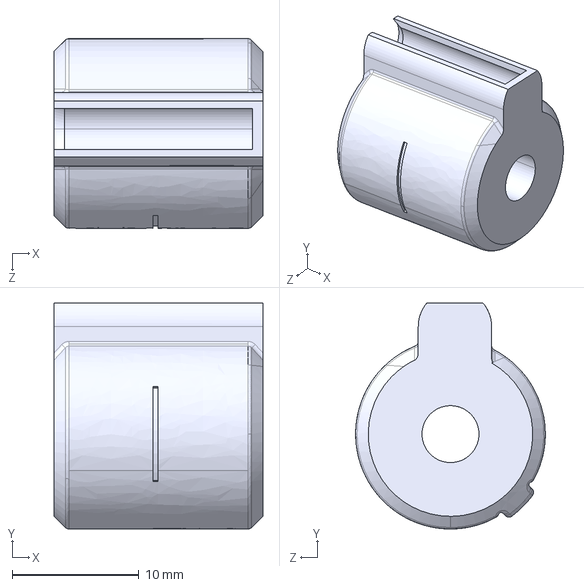
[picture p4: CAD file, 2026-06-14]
addons/PFS/3D files/piston.STEP
16.5 x 17.9 x 15.0 mm

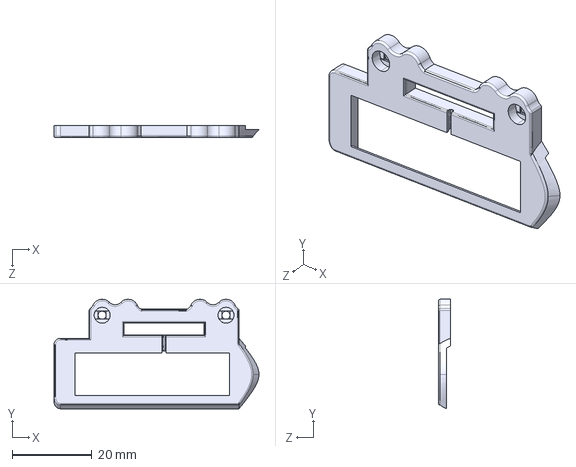
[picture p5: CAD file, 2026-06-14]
addons/PFS/3D files/body-cap.STEP
51.3 x 27.4 x 3.04 mm

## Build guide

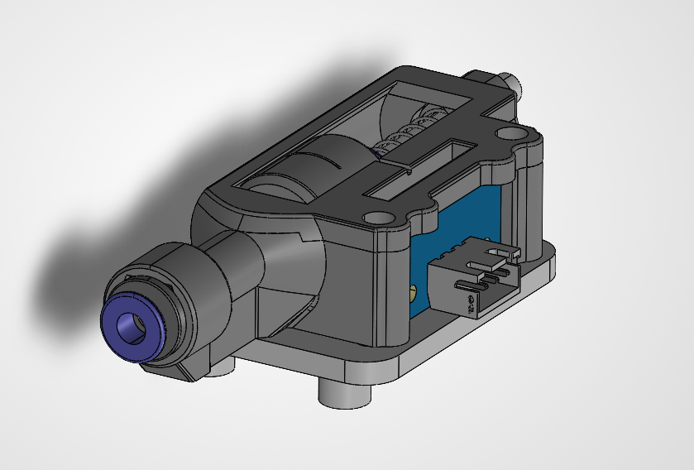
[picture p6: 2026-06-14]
addons/PFS/3D files/assembly.png

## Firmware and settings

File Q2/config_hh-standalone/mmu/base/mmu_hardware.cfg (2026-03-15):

########################################################################################################################
# Happy Hare MMU Software
#
# EDIT THIS FILE BASED ON YOUR SETUP
#
# Copyright (C) 2022-2025  moggieuk#6538 (discord)
#                          moggieuk@hotmail.com
# This file may be distributed under the terms of the GNU GPLv3 license.
#
# Goal: Happy Hare MMU hardware config file with config for BTT ViViD MCU board
#
# (\_/)
# ( *,*)
# (")_(") Happy Hare Ready
#
#
# Notes about setup of common external MCUs can be found here:
#  https://github.com/moggieuk/Happy-Hare/blob/main/doc/mcu_notes.md
# 
# Note about "touch" endstops: Happy Hare provides extremely flexible homing options using both single steppers or
# synced steppers. The "touch" option leverages stallguard and thus requires the appropriate 'diag_pin' and stallguard
# parameters set on the TMC driver section. If you have the diag_pin exposed, it is harmless to define this because
# they will only be used when explicitly needed and configured.
#
# Touch option for each stepper provides these benefits / possibilities (experimental):
#  - on extruder stepper allows for the automatic detection of the nozzle!
#  - on selector stepper allows for the automatic detection of filament stuck in the gate and subsequent recovery
#  - on gear stepper allows for the automatic detection of the extruder entrance
#
# In summary, "touch" homing with your MMU is an advanced option that requires patience and careful tuning. Everything
# works with regular endstops and there are workaround options for certain homing points (like extruder entry) in
# the absence of any endstop. I'm really interested in creative setups. Ping me on Discord (moggieuk#6538)
#
# See 'mmu.cfg' for serial definition and pins aliases
#
# HOMING CAPABLE EXTRUDER (VERY ADVANCED) -----------------------------------------------------------------------------
# With Happy Hare installed even the extruder can be homed. You will find the usual 'endstop' parameters can be added
# to your '[extruder]' section.  Useless you have some clever load cell attached to your nozzle it only really makes
# sense to configure stallguard style "touch" homing. To do this add lines similar to this to your existing
# '[extruder]' definition in printer.cfg.
#
#    [extruder]
#    endstop_pin: tmc2209_extruder:virtual_endstop
#
# Also be sure to add the appropriate stallguard config to the TMC section, e.g.
#
#    [tmc2209 extruder]
#    diag_pin: E_DIAG		# Set to MCU pin connected to TMC DIAG pin for extruder
#    driver_SGTHRS: 100		# 255 is most sensitive value, 0 is least sensitive
#
# Happy Hare will take care of the rest and add a 'mmu_ext_touch' endstop automatically
#


# MMU MACHINE / TYPE ---------------------------------------------------------------------------------------------------
# ███╗   ███╗███╗   ███╗██╗   ██╗    ███╗   ███╗ █████╗  ██████╗██╗  ██╗██╗███╗   ██╗███████╗
# ████╗ ████║████╗ ████║██║   ██║    ████╗ ████║██╔══██╗██╔════╝██║  ██║██║████╗  ██║██╔════╝
# ██╔████╔██║██╔████╔██║██║   ██║    ██╔████╔██║███████║██║     ███████║██║██╔██╗ ██║█████╗  
# ██║╚██╔╝██║██║╚██╔╝██║██║   ██║    ██║╚██╔╝██║██╔══██║██║     ██╔══██║██║██║╚██╗██║██╔══╝  
# ██║ ╚═╝ ██║██║ ╚═╝ ██║╚██████╔╝    ██║ ╚═╝ ██║██║  ██║╚██████╗██║  ██║██║██║ ╚████║███████╗
# ╚═╝     ╚═╝╚═╝     ╚═╝ ╚═════╝     ╚═╝     ╚═╝╚═╝  ╚═╝ ╚═════╝╚═╝  ╚═╝╚═╝╚═╝  ╚═══╝╚══════╝
[mmu_machine]

# Number of selectable gate on (each) MMU. Generally this is a single number, but with multi-mmu (type-B) setups
# it can be a comma separated list of the number of gates per unit.
# E.g. 'num_gates: 4,4,2' for a 2xBox Turtle and 1xNight Owl multiplexed setup
#
num_gates: 4 # "4, 4" for 2x Box, "4, 4, 4" for 3x Box, etc.

# MMU Vendor & Version is used to automatically configure some parameters and validate configuration
# If custom set to "Other" and uncomment the additional parameters below
#
mmu_vendor: Other				# MMU family
mmu_version: 1.0			# MMU hardware version number (add mod suffix documented above)

# The following attributes are set internally from vendor/version above. Only uncomment to customize the vendor
# default or for custom ("Other") designs
#
selector_type: VirtualSelector		# E.g. LinearSelector (type-A), VirtualSelector (type-B), MacroSelector, RotarySelector, ...
variable_bowden_lengths: 0		# 1 = If MMU design has different bowden lengths per gate, 0 = bowden length is the same
variable_rotation_distances: 0		# 1 = If MMU design has dissimilar drive/BMG gears, thus rotation distance, 0 = One drive gear (e.g. Tradrack)
require_bowden_move: 1			# 1 = If MMU design has bowden move that is included in load/unload, 0 = zero length bowden (skip bowden move)
filament_always_gripped: 1		# 1 = Filament is always trapped by MMU (most type-B designs), 0 = MMU can release filament
has_bypass: 0				# 1 = Bypass gate available, 0 = No filament bypass possible

# Fullname of environment sensor for MMU filament storage (displays temp and humidity in UI). Leave empty if sensor is not fitted
# Polls for "temperature" and "humidity"
# E.g. If you have a section like this: [temperature_sensor MMU_enclosure]
#      Set: environment_sensor: temperature_sensor MMU_enclosure
environment_sensor: temperature_sensor box1_env
# TEMP - Happy Hare does not yet support multibox env sensor

# Full name of filament heater object. Leave empty if heater is not fitted
# E.g. If you have a section like this: [heater_generic MMU_heater]
#      Set: filament_heater: heater_generic MMU_heater
filament_heater: heater_generic box1_heater
# TEMP - Happy Hare does not yet support multibox filament heater

# PER-GATE heaters and environment sensors. Some modular MMU designs have per-gate control (e.g. EMU). For this type of MMU, leave
# 'environment_sensor' and 'filament_heater' empty and define a list of heaters and sensors here. Note the length of the list must
# match the number of gates. Leave this settings empty if defining a single sensor/heater.
environment_sensors:                    # Comma separated list of full environment sensor object names
filament_heaters:                       # Comma separated list of full heater object names
max_concurrent_heaters: 1               # Limit the number of simultaneously active heaters (power/PSU protection)

homing_extruder: 1			# CAUTION: Normally this should be 1. 0 will disable the homing extruder capability


# FILAMENT DRIVE GEAR STEPPER(S) --------------------------------------------------------------------------------------
#  ██████╗ ███████╗ █████╗ ██████╗
# ██╔════╝ ██╔════╝██╔══██╗██╔══██╗
# ██║  ███╗█████╗  ███████║██████╔╝
# ██║   ██║██╔══╝  ██╔══██║██╔══██╗
# ╚██████╔╝███████╗██║  ██║██║  ██║
#  ╚═════╝ ╚══════╝╚═╝  ╚═╝╚═╝  ╚═╝
#
# Note that 'toolhead' & 'mmu_gear' endstops will automatically be added if a toolhead sensor or gate sensor is defined
#

####################
### BOX 1 MOTORS ###

# Filament Drive Gear_0 --------------------------
# stock Qidi Box does not have the UART interface to stepper drivers connected

[stepper_mmu_gear]
step_pin: mmu:PC14
dir_pin: mmu:PC13
enable_pin: !mmu:PC15
rotation_distance: 13.6
step_pulse_duration:0.000000100
microsteps: 16

# Filament Drive Gear_1 --------------------------
# stock Qidi Box does not have the UART interface to stepper drivers connected

[stepper_mmu_gear_1]
step_pin: mmu:PB9
dir_pin: mmu:PB8
enable_pin: !mmu:PC0
rotation_distance: 13.6
step_pulse_duration:0.000000100
microsteps: 16

# Filament Drive Gear_2 --------------------------
# stock Qidi Box does not have the UART interface to stepper drivers connected

[stepper_mmu_gear_2]
step_pin: mmu:PC12
dir_pin: mmu:PC11
enable_pin: !mmu:PD2
rotation_distance: 13.6
step_pulse_duration:0.000000100
microsteps: 16

# Filament Drive Gear_3 --------------------------
# stock Qidi Box does not have the UART interface to stepper drivers connected

[stepper_mmu_gear_3]
step_pin: mmu:PC8
dir_pin: mmu:PB2
enable_pin: !mmu:PC10
rotation_distance: 13.6
step_pulse_duration:0.000000100
microsteps: 16

### BOX 1 MOTORS END ###
########################

####################
### BOX 2 MOTORS ###
### uncomment the [stepper_mmu1_gear] sections if using a second box

## Filament Drive Gear_0 --------------------------
## stock Qidi Box does not have the UART interface to stepper drivers connected

#[stepper_mmu1_gear]
#step_pin: mmu1:PC14
#dir_pin: mmu1:PC13
#enable_pin: !mmu1:PC15
#rotation_distance: 13.6
#step_pulse_duration:0.000000100
#microsteps: 16

## Filament Drive Gear_1 --------------------------
## stock Qidi Box does not have the UART interface to stepper drivers connected

#[stepper_mmu1_gear_1]
#step_pin: mmu1:PB9
#dir_pin: mmu1:PB8
#enable_pin: !mmu1:PC0
#rotation_distance: 13.6
#step_pulse_duration:0.000000100
#microsteps: 16

## Filament Drive Gear_2 --------------------------
## stock Qidi Box does not have the UART interface to stepper drivers connected
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

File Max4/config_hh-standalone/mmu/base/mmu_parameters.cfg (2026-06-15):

########################################################################################################################
# Happy Hare MMU Software
#
# Template file for MMU's with Virtual Selector (Type-B designs like Box Turtle, Night Owl, Angry Beaver, ...)
# This file omits selector and selector-servo configuration and a few other options that don't make sense
#
# EDIT THIS FILE BASED ON YOUR SETUP
#
# Copyright (C) 2022-2026  moggieuk#6538 (discord)
#                          moggieuk@hotmail.com
# This file may be distributed under the terms of the GNU GPLv3 license.
#
# Goal: Main configuration parameters for the klipper module
#
# (\_/)
# ( *,*)
# (")_(") Happy Hare Ready
#
# Notes:
#   Macro configuration is specified separately in 'mmu_macro_vars.cfg'.
#   Full details in https://github.com/moggieuk/Happy-Hare/tree/main/doc/configuration.md
#
[mmu]
happy_hare_version: 3.42			# Don't mess, used for upgrade detection

# MMU Hardware Limits --------------------------------------------------------------------------------------------------
# ██╗     ██╗███╗   ███╗██╗████████╗███████╗
# ██║     ██║████╗ ████║██║╚══██╔══╝██╔════╝
# ██║     ██║██╔████╔██║██║   ██║   ███████╗
# ██║     ██║██║╚██╔╝██║██║   ██║   ╚════██║
# ███████╗██║██║ ╚═╝ ██║██║   ██║   ███████║
# ╚══════╝╚═╝╚═╝     ╚═╝╚═╝   ╚═╝   ╚══════╝
#
# Define the physical limits of your MMU. These settings will be respected regardless of individual speed settings.
#
gear_max_velocity: 240			# Never to be exceeded gear velocity regardless of specific parameters
gear_max_accel: 1500			# Never to be exceeded gear acceleration regardless of specific parameters


# Logging --------------------------------------------------------------------------------------------------------------
# ██╗      ██████╗  ██████╗  ██████╗ ██╗███╗   ██╗ ██████╗ 
# ██║     ██╔═══██╗██╔════╝ ██╔════╝ ██║████╗  ██║██╔════╝ 
# ██║     ██║   ██║██║  ███╗██║  ███╗██║██╔██╗ ██║██║  ███╗
# ██║     ██║   ██║██║   ██║██║   ██║██║██║╚██╗██║██║   ██║
# ███████╗╚██████╔╝╚██████╔╝╚██████╔╝██║██║ ╚████║╚██████╔╝
# ╚══════╝ ╚═════╝  ╚═════╝  ╚═════╝ ╚═╝╚═╝  ╚═══╝ ╚═════╝ 
#
# log_level & logfile_level can be set to one of (0 = essential, 1 = info, 2 = debug, 3 = trace, 4 = stepper moves)
# Generally you can keep console logging to a minimal whilst still sending debug output to the mmu.log file
# Increasing the console log level is only really useful during initial setup to save having to constantly open the log file
# Note: that it is not recommended to keep logging at level greater that 2 (debug) if not debugging an issue because
# of the additional overhead
#
log_level: 1
log_file_level: 3			# Can also be set to -1 to disable log file completely
log_statistics: 1 			# 1 to log statistics on every toolchange (default), 0 to disable (but still recorded)
log_visual: 1				# 1 log visual representation of filament, 0 = disable
log_startup_status: 1			# Whether to log tool to gate status on startup, 1 = summary (default), 0 = disable
log_m117_messages: 0			# Whether send toolchange message via M117 to screen


# Movement speeds ------------------------------------------------------------------------------------------------------
# ███████╗██████╗ ███████╗███████╗██████╗ ███████╗
# ██╔════╝██╔══██╗██╔════╝██╔════╝██╔══██╗██╔════╝
# ███████╗██████╔╝█████╗  █████╗  ██║  ██║███████╗
# ╚════██║██╔═══╝ ██╔══╝  ██╔══╝  ██║  ██║╚════██║
# ███████║██║     ███████╗███████╗██████╔╝███████║
# ╚══════╝╚═╝     ╚══════╝╚══════╝╚═════╝ ╚══════╝
#
# Long moves are faster than the small ones and used for the bulk of the bowden movement. You can set two fast load speeds
# depending on whether pulling from the spool or filament buffer (if fitted and not the first time load). This can be helpful
# in allowing faster loading from buffer and slower when pulling from the spool because of the additional friction (prevents
# loosing steps). Unloading speed can be tuning if you have a rewinder system that imposes additional limits.
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

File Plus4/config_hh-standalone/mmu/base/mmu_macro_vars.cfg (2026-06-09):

########################################################################################################################
# Happy Hare MMU Software
#
# EDIT THIS FILE BASED ON YOUR SETUP
#
# Copyright (C) 2022-2026  moggieuk#6538 (discord)
#                          moggieuk@hotmail.com
# This file may be distributed under the terms of the GNU GPLv3 license.
#
# Goal: Happy Hare supporting MACRO configuration
#
# (\_/)
# ( *,*)
# (")_(") Happy Hare Ready
#
#
# Supporting set of macros supplied with Happy Hare can be customized by editing the macro "variables" declared here.
#
# This configuration will automatically retained and upgraded between releases (a backup of previous config files will
# always be made for your reference). If you want to customize macros beyond what is possible through these variables
# it is highly recommended you copy the macro to a new name and change the callback macro name in 'mmu_parameters.cfg'
# That way the default macros can still be upgraded but your customization will be left intact
#


# PERSISTED STATE ---------------------------------------------------------
# Happy Hare stores configuration and state in the klipper variables file.
# Since klipper can only be a single 'save_variables' file, if you already
# have one you will need to merge the two and point this appropriately.
#
[save_variables]
filename: ~/printer_data/config/mmu/mmu_vars.cfg


# NECESSARY KLIPPER OVERRIDES ---------------------------------------------
# ██╗  ██╗██╗     ██╗██████╗ ██████╗ ███████╗██████╗ 
# ██║ ██╔╝██║     ██║██╔══██╗██╔══██╗██╔════╝██╔══██╗
# █████╔╝ ██║     ██║██████╔╝██████╔╝█████╗  ██████╔╝
# ██╔═██╗ ██║     ██║██╔═══╝ ██╔═══╝ ██╔══╝  ██╔══██╗
# ██║  ██╗███████╗██║██║     ██║     ███████╗██║  ██║
# ╚═╝  ╚═╝╚══════╝╚═╝╚═╝     ╚═╝     ╚══════╝╚═╝  ╚═╝
#
# These supplemental settings essentially disable klipper's built in
# extrusion limits and is necessary when using an MMU
[extruder]
max_extrude_only_distance: 200
max_extrude_cross_section: 50

# For dialog prompts and progress in Mainsail. Requires Mainsail version >= v2.9.0
[respond]

# Other Happy Hare prerequisites. Harmless if already defined elsewhere in user config
[display_status]
[pause_resume]
[virtual_sdcard]
path: ~/printer_data/gcodes
#on_error_gcode: CANCEL_PRINT


# PRINT START/END ---------------------------------------------------------
# ██████╗ ██████╗ ██╗███╗   ██╗████████╗    ███████╗████████╗ █████╗ ██████╗ ████████╗
# ██╔══██╗██╔══██╗██║████╗  ██║╚══██╔══╝    ██╔════╝╚══██╔══╝██╔══██╗██╔══██╗╚══██╔══╝
# ██████╔╝██████╔╝██║██╔██╗ ██║   ██║       ███████╗   ██║   ███████║██████╔╝   ██║   
# ██╔═══╝ ██╔══██╗██║██║╚██╗██║   ██║       ╚════██║   ██║   ██╔══██║██╔══██╗   ██║   
# ██║     ██║  ██║██║██║ ╚████║   ██║       ███████║   ██║   ██║  ██║██║  ██║   ██║   
# ╚═╝     ╚═╝  ╚═╝╚═╝╚═╝  ╚═══╝   ╚═╝       ╚══════╝   ╚═╝   ╚═╝  ╚═╝╚═╝  ╚═╝   ╚═╝   
#   (base/mmu_software.cfg)
#
[gcode_macro _MMU_SOFTWARE_VARS]
description: Happy Hare optional configuration for print start/end checks
gcode: # Leave empty

# These variables control the behavior of the MMU_START_SETUP and MMU_START_LOAD_INITIAL_TOOL macros
variable_user_pre_initialize_extension      : ''	; Executed at start of MMU_START_SETUP. Commonly G28 to home
variable_home_mmu                           : False	; True/False, Whether to home mmu before print starts
variable_check_gates                        : False	; True/False, Whether to check filament is loaded in all gates used
variable_load_initial_tool                  : True	; True/False, Whether to automatically load initial tool
#
# Automapping strategy to apply slicer tool map to find matching MMU gate (will adjust tool-to-gate map). Options are:
#   'none'           - don't automap (i.e. don't update tool-to-gate map)
#   'filament_name'  - exactly match on case insensitive filament name
#   'material'       - exactly match on material
#   'color'          - exactly match on color (with same material)
#   'closest_color'  - match to closest available filament color (with same material)
#   'spool_id'       - exactly match on spool_id  [FUTURE]
variable_automap_strategy                   : "none"	; none|filament_name|material|color|closest_color|spool_id

# These variables control the behavior of the MMU_END macro
variable_user_print_end_extension           : ''	; Executed at start of MMU_END. Good place to move off print
variable_unload_tool                        : True	; True/False, Whether to unload the tool at the end of the print
variable_reset_ttg                          : False	; True/False, Whether reset TTG map at end of print
variable_dump_stats                         : True	; True/False, Whether to display print stats at end of print


# STATE MACHINE CHANGES ---------------------------------------------------
# ███████╗████████╗ █████╗ ████████╗███████╗     ██████╗██╗  ██╗ █████╗ ███╗   ██╗ ██████╗ ███████╗
# ██╔════╝╚══██╔══╝██╔══██╗╚══██╔══╝██╔════╝    ██╔════╝██║  ██║██╔══██╗████╗  ██║██╔════╝ ██╔════╝
# ███████╗   ██║   ███████║   ██║   █████╗      ██║     ███████║███████║██╔██╗ ██║██║  ███╗█████╗  
# ╚════██║   ██║   ██╔══██║   ██║   ██╔══╝      ██║     ██╔══██║██╔══██║██║╚██╗██║██║   ██║██╔══╝  
# ███████║   ██║   ██║  ██║   ██║   ███████╗    ╚██████╗██║  ██║██║  ██║██║ ╚████║╚██████╔╝███████╗
# ╚══════╝   ╚═╝   ╚═╝  ╚═╝   ╚═╝   ╚══════╝     ╚═════╝╚═╝  ╚═╝╚═╝  ╚═╝╚═╝  ╚═══╝ ╚═════╝ ╚══════╝
#   (base/mmu_state.cfg)
#
[gcode_macro _MMU_STATE_VARS]
description: Happy Hare configuration for state change hooks
gcode: # Leave empty

# You can extend functionality to all Happy Hare state change or event
# macros by adding a command (or call to your gcode macro).
# E.g for additional LED logic or consumption counters
variable_user_action_changed_extension      : ''	; Executed after default logic with duplicate params
variable_user_print_state_changed_extension : ''	; Executed after default logic with duplicate params
variable_user_mmu_event_extension           : ''	; Executed after default logic with duplicate params

# Maintenance warning limits (consumption counters)
variable_servo_down_limit                   : 5000      ; Set to -1 for no limit / disable warning
variable_cutter_blade_limit                 : 3000      ; Set to -1 for no limit / disable warning


# SEQUENCE MACRO - PARKING MOVEMENT AND TOOLCHANGE CONTROL ----------------
# ███╗   ███╗ ██████╗ ██╗   ██╗███████╗███╗   ███╗███████╗███╗   ██╗████████╗
# ████╗ ████║██╔═══██╗██║   ██║██╔════╝████╗ ████║██╔════╝████╗  ██║╚══██╔══╝
# ██╔████╔██║██║   ██║██║   ██║█████╗  ██╔████╔██║█████╗  ██╔██╗ ██║   ██║   
# ██║╚██╔╝██║██║   ██║╚██╗ ██╔╝██╔══╝  ██║╚██╔╝██║██╔══╝  ██║╚██╗██║   ██║   
# ██║ ╚═╝ ██║╚██████╔╝ ╚████╔╝ ███████╗██║ ╚═╝ ██║███████╗██║ ╚████║   ██║   
# ╚═╝     ╚═╝ ╚═════╝   ╚═══╝  ╚══════╝╚═╝     ╚═╝╚══════╝╚═╝  ╚═══╝   ╚═╝   
# Configure carefully if you 'enable_park: True'
#   (base/mmu_sequence.cfg)
#
[gcode_macro _MMU_SEQUENCE_VARS]
description: Happy Hare sequence macro configuration variables
gcode: # Leave empty
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

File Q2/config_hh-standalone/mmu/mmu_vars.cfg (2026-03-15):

[Variables]
mmu__revision = 2403
mmu_calibration_bowden_home = 'mmu_gate'
mmu_calibration_bowden_lengths = [656.5, 656.5, 656.5, 656.5]
mmu_gear_rotation_distances = [13.6, 13.6, 13.6, 13.6]
mmu_state_enable_endless_spool = 1
mmu_state_endless_spool_groups = [0, 1, 2, 3]
mmu_state_filament_pos = 0
mmu_state_filament_remaining = 0
mmu_state_filament_remaining_color = '080ee4ff'
mmu_state_gate_color = ['e3fa05ff', 'e6e9e9e6', '02101FE3', '080ee4ff']
mmu_state_gate_filament_name = ['Plymaker', 'Polymaker', 'Polymaker', 'Polymaker']
mmu_state_gate_material = ['PLA', 'PLA', 'PLA', 'PLA']
mmu_state_gate_selected = 3
mmu_state_gate_speed_override = [100, 100, 100, 100]
mmu_state_gate_spool_id = [-1, -1, -1, -1]
mmu_state_gate_status = [2, 2, 1, 2]
mmu_state_gate_temperature = [220, 220, 220, 220]
mmu_state_last_tool = 3
mmu_state_tool_selected = 3
mmu_state_tool_to_gate_map = [0, 1, 2, 3]
mmu_statistics_counters = {'mmu_restarts': {'count': 268, 'limit': -1, 'warning': ''}}
mmu_statistics_gate_0 = {'pauses': 6, 'loads': 36, 'load_distance': 0.0, 'load_delta': 0.0, 'unloads': 41, 'unload_distance': 0.0, 'unload_delta': 0.0, 'load_failures': 15, 'unload_failures': 4, 'quality': -1.0}
mmu_statistics_gate_1 = {'pauses': 6, 'loads': 27, 'load_distance': 0.0, 'load_delta': 0.0, 'unloads': 33, 'unload_distance': 0.0, 'unload_delta': 0.0, 'load_failures': 12, 'unload_failures': 11, 'quality': -1.0}
mmu_statistics_gate_2 = {'pauses': 0, 'loads': 10, 'load_distance': 0.0, 'load_delta': 0.0, 'unloads': 11, 'unload_distance': 0.0, 'unload_delta': 0.0, 'load_failures': 0, 'unload_failures': 0, 'quality': -1.0}
mmu_statistics_gate_3 = {'pauses': 0, 'loads': 3, 'load_distance': 0.0, 'load_delta': 0.0, 'unloads': 6, 'unload_distance': 0.0, 'unload_delta': 0.0, 'load_failures': 1, 'unload_failures': 0, 'quality': -1.0}
mmu_statistics_swaps = {'pre_unload': 53.6, 'form_tip': 1567.69, 'post_unload': 75.23, 'unload': 3051.61, 'pre_load': 39.63, 'purge': 167.8, 'post_load': 856.55, 'load': 2382.92, 'total_swaps': 31, 'swaps_since_pause': 2, 'swaps_since_pause_record': 15, 'total': 1763.48, 'total_pauses': 12, 'pause': 2342.65}
qdc_ai_error_code = 'pei=0 status=0 time=1765765600'
z_offset = 0.05000000000000001

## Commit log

2025-12-03 Cutting changed to external macro
    [box_hh_macros.cfg, mmu_parameters.cfg]
2025-12-08 Fix tool change macro conditions
    [mmu_macro_vars.cfg]
2025-12-08 Fix eject retraction distance
    [mmu_parameters.cfg]
2025-12-08 Add pressure relief for cutting, retract before cut
    [box_hh_macros.cfg]
2025-12-13 Moved hardware definitions to mmu_hardware for encapsulation LED implementation AHT20_F fix Speeds increased
    [box_hh.cfg, bunnybox_macros.cfg, mmu_hardware.cfg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]
2025-12-14 gcode macros adding park and typo fixes
    [bunnybox_macros.cfg]
2025-12-15 AHT fix for compatibility with screen Testing macros added
    [bunnybox_macros.cfg, mmu_leds.cfg, mmu_macro_vars.cfg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]
2026-01-09 Stock mmu_leds.cfg, effects now defined in mmu_hardware.cfg
    [mmu_leds.cfg]
2026-01-11 Minor macro changes
    [bunnybox_macros.cfg]
2026-01-16 Added Happy Hare configuration variants
    [blobifier.cfg, blobifier_hw.cfg, bunnybox_macros.cfg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]
2026-02-04 WIP: Macro and config improvements
    [bunnybox_macros.cfg, mmu_macro_vars.cfg, mmu_parameters.cfg]
2026-02-10 tip formings and readme update
    [mmu_hardware.cfg, mmu_macro_vars.cfg, mmu_parameters.cfg]
2026-02-21 cutter initial config
    [mmu_hardware.cfg, mmu_macro_vars.cfg, mmu_parameters.cfg]
2026-02-26 Cutting tuning
    [mmu_macro_vars.cfg, mmu_parameters.cfg]
2026-02-26 environmental sensor fix
    [mmu_hardware.cfg]
2026-02-27 box environmental sensor fix for Kalico
    [mmu_hardware.cfg]
2026-03-01 New config-only AHT20F handling
    [mmu_hardware.cfg]
2026-03-01 Conch tip forming config
    [mmu_hardware.cfg, mmu_macro_vars.cfg]
2026-03-01 Remove qidi-like configs - not continuing them
    [blobifier.cfg, blobifier_hw.cfg, bunnybox_macros.cfg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]
2026-03-01 Update Qidi Box pinout with microcontroller details
    Added information about the STM32F402RCT6 microcontroller and clarified the stepper motor driver configuration.
2026-03-01 Changed tip forming defaults - reverted my mistake (conch defaults are actually the defaults)
    [mmu_macro_vars.cfg]
2026-03-07 Update maximum homing distances in mmu_parameters.cfg
    [mmu_parameters.cfg]
2026-03-08 Q2 cleanup
    [PARK_PURGE_WIPE.cfg, Purge_Servo.cfg, blobifier.cfg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]
2026-03-08 Max4 initial commit
    [blobifier.cfg, blobifier_hw.cfg, bunnybox_macros.cfg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]
2026-03-08 environment sensor instructions
2026-03-09 Max4 toolhead measurements
    [mmu_macro_vars.cfg, mmu_parameters.cfg]
2026-03-11 Create dfu_flash
    Instructions for DFU flashing the MCU with mainline Klipper
2026-03-15 initial q2 configs
    [blobifier.cfg, blobifier_hw.cfg, bunnybox_macros.cfg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]
2026-03-15 q2 initial configs
    [bunnybox_macros.cfg]
2026-03-26 minor P4 tuning of cutting
    [mmu_macro_vars.cfg]
2026-04-24 Add revert-to-stock option to all three installers
    Detects an existing bunnybox/Happy Hare install and offers a
    reinstall/revert/cancel menu. Revert restores printer.cfg from the
    oldest backup_hh_* directory (presumed closest to stock) and preserves
    the current bunnybox state under backup_revert_<ts> so the revert
    itself is undoable. Max4 also restores klipper-macros-qd/; Q2 and
    Plus4 restore gcode_macro.cfg.
2026-04-24 Advise removing duplicated sensors to avoid timer-too-close
    Plus4 stock [hall_filament_width_sensor] reads the same ADC pins
    (PA2/PA3) as the MMU's extruder_switch_pin/2. Two ADC readers on the
    same pins can cause MCU Timer too close crashes, so the installer and
    README now strongly recommend commenting out the whole section.
    Q2 and Max4 use digital switches (THR:PA1 / THR:PA0), where the timing
    risk is negligible, so they get a softer note suggesting the stock
    filament_switch_sensor can be commented out for cleanliness once the
    MMU is verified.
2026-04-24 PLR disabling
    [bunnybox_macros.cfg]
2026-04-24 Max4 updates
    [bunnybox_macros.cfg]
2026-05-19 Wrap [idle_timeout] gcode with HH drying-state exclusion
    The stock idle_timeout gcode (Qidi PRINT_END or Klipper's implicit
    TURN_OFF_HEATERS+M84) will kill the box heater mid-cycle when a user
    runs MMU_HEATER DRY=1 with an idle_timeout shorter than the drying
    duration. Wrap the existing gcode so that, when drying is active, only
    the main printer heaters are zeroed; otherwise the original gcode runs
    unchanged.
    Install scripts (Plus4/Q2/Max4): explicitly check for [idle_timeout],
    prompt the user, then either wrap an existing gcode: block or insert
    one if the section relied on Klipper's default. Idempotent — re-running
    the installer detects the wrap and skips.
    Docs: add the diff snippet to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
2026-05-19 Scope drying-exclusion idempotency check to [idle_timeout] section
    The previous file-wide substring check matched any occurrence of
    'printer.mmu.drying_state' in printer.cfg — including commented-out
    remnants from a prior attempt or unrelated macros (e.g. a custom
    runout_gcode that mentions drying state). That caused the wrap to be
    falsely skipped on testers' machines whose printer.cfg already contained
    the substring outside [idle_timeout].
    Reading the check now considers only uncommented lines inside the
    [idle_timeout] section, so it triggers only when the section itself has
    already been wrapped.
2026-05-19 Numbered selection for serial device prompt
    The fallback prompt (when QIDI_BOX autodetection misses) used to list
    devices with ls and require the full path. List them numbered now and
    accept either a number or a pasted path.
2026-05-23 Increase the cutting pretension distance in line with Qidi baseline on Plus4
    [mmu_macro_vars.cfg]
2026-06-08 Adjust variable_retract_length to 5mm
    Reduced variable_retract_length for better filament management.
    [mmu_macro_vars.cfg]
2026-06-14 BOX_MOVE_TO_TRASH explicitly added to avoid Qidi's MOVE_TO_TRASH dependancy
    [bunnybox_macros.cfg]
2026-06-14 Proportional Feedback Sensor addon
    [body-cap.STEP, mounting-plate.STEP, piston.STEP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]
2026-06-14 Filament sensor commenting improvement
2026-06-14 Fixing pause on runout leading to instant cancel on Plus4
    [mmu_parameters.cfg]
2026-06-15 Smart update for Plus4 installer: 3-way merge instead of overwrite
    Re-running the installer on an existing install used to 'cp -r mmu/' over the live config, wiping user tuning and — critically — mmu_vars.cfg, Happy Hare's calibration/state store, forcing a full re-calibration on every update.
    Now the installer stamps each install with a pristine base snapshot (.bunnybox_base) and a manifest (.bunnybox_manifest). On update it does a per-file 3-way merge: mmu_vars.cfg is always preserved; untouched-locally files auto-update; locally-edited-but-unchanged-upstream files are kept; both-changed files are merged, with collisions prompting per-file (keep yours / take new / write *.bbmerge mark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
2026-06-15 Rescope Plus4 smart-update to BunnyBox-owned files; refresh mirrored HH configs
    Happy Hare's install.sh (run in upgrade mode right after our copy) already owns most of the mmu/ tree: it symlinks the logic files (cut_tip, sequence, software, ...) from ~/Happy-Hare and carries for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
    Smart-update is now scoped to the files HH leaves frozen and BunnyBox truly owns: mmu/base/mmu_hardware.cfg, mmu/base/mmu.cfg, mmu/addons/*_hw.cfg, and bunnybox_macros.cfg. Added bb_managed_f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
    [client_macros.cfg, mmu_cut_tip.cfg, mmu_form_tip.cfg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]
2026-06-15 Port smart-update (3-way merge) to Q2 and Max4 installers
    Applies the same rescoped smart-update as Plus4: on re-install, the Bunny Box-owned files (mmu/base/mmu_hardware.cfg, mmu/base/mmu.cfg, mmu/addons/*_hw.cfg, bunnybox_macros.cfg) are 3-way-merged agai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
    Machinery is byte-identical across the three scripts (only BB_PRINTER differs); printer-specific install logic is untouched.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
2026-06-15 Lower default drying target humidity to 5% (was 25% Plus4 / 10% Q2+Max4)
    25% is far too high a goal for a drying cycle to ever meaningfully reach; 5% is a sensible strong default. Set consistently across all three printers. Note: heater_default_humidity lives in mmu_parameters.cfg, which Happy Hare carries forward on upgrade, so existing installs keep their current value — this only changes the default for fresh installs.
    [mmu_parameters.cfg]
2026-06-15 Point Q2 and Max4 installers at Qidi Box HH fork; rename "WIP repo" to "Qidi Box fork"
    Q2 and Max4 were cloning mainline moggieuk/Happy-Hare (main branch), which
    lacks the drying feature, so the recent drying-target changes had no effect.
    Switch both installers and manual-install READMEs to the Wazzup77/Happy-Hare
    fork on the bunnybox branch, matching Plus4.
    Also rename the user-facing "WIP repo/fork" label to "Qidi Box fork" across
    all three printers.
2026-06-20 Plus4 installer: auto-detect extruder hall sensor MCU (fixes FreeDi false runout)
    On FreeDi/Kalico the Plus4 toolhead is a separate Klipper MCU, so the bare
    `extruder_switch_pin: PA2` in mmu_hardware.cfg binds to the *main* MCU - an
    unconnected pin that floats and triggers a false "filament runout at extruder"
    the instant a print starts. The stock [hall_filament_width_sensor] reads the
    real sensor on Toolhead:PA2/PA3.
    install-bb-p4.sh now captures the stock sensor's adc1/adc2, comments out the
    entire [hall_filament_width_sensor] section to free the ADC pins, and copies
    those exact pin specs into extruder_switch_pin/extruder_switch_pin2. This is
    correct on both Qidi-stock (bare PA2) and Free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
2026-06-20 Q2/Max4 installers: detect stock filament switch pin instead of hardcoding THR
    Mirror the Plus4 auto-detect for the Q2 and Max4 installers. These use a digital
    [filament_switch_sensor filament_switch_sensor] (switch_pin: !THR:PAx) shared
    with the MMU via [duplicate_pin_override], so the toolhead-MCU pin name was
    hardcoded as THR in two places: the override pin and mmu_hardware.cfg's
    extruder_switch_pin. On FreeDi/Kalico the toolhead MCU may be named differently
    (e.g. Toolhead), making the hardcoded THR fail to load with "MCU 'THR' not
    found".
    modify_printer_cfg now reads the stock sensor's switch_pin and feeds it into
    both the duplicate_pin_override pin (bare) and extruder_switch_pin (full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
2026-09-01 Add tension variables to Q2 configs
